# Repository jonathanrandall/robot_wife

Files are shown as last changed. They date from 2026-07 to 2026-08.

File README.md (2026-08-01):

# Robot Wife — Jessica

<p align="center">
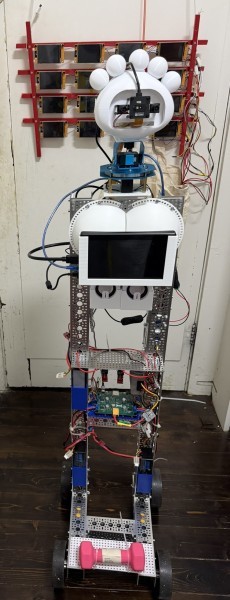
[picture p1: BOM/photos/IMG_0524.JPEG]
  
  &nbsp;&nbsp;
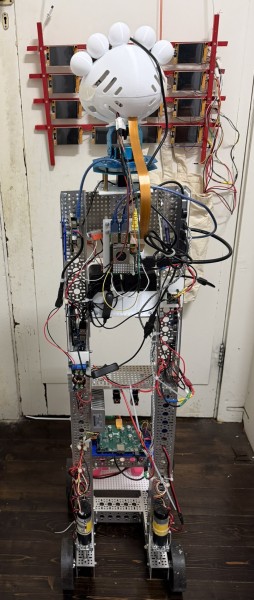
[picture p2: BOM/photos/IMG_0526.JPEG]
  
</p>

A personal robotics project: a conversational, physically expressive companion robot called **Jessica**. She drives around on four wheels, moves her head with a pan-tilt servo, lights up her LED hair, sees through a stereo USB camera, listens via microphone, and speaks through a USB speaker — all coordinated by a Raspberry Pi 5 running ROS 2 and an ESP32-S3 handling the low-level motor and servo control.

---

## Hardware Overview

| Component | Details |
|---|---|
| **Brain** | Raspberry Pi 5 |
| **Motor / Servo Controller** | Custom ESP32-S3 PCB (PlatformIO/Arduino firmware) |
| **Drive system** | 4-wheel differential drive, 4× motors with 1425 CPR quadrature encoders |
| **Motor drivers** | 4× VNH7040 H-bridge ICs controlled via MCP23017 I2C GPIO expander — [GitHub repo](https://github.com/jonathanrandall/four_motor_controller) containing KiCad schematic, PCB layout and bill of materials / [build video](https://youtu.be/qtjofj0y1YY) |
| **Head** | [Poppy Eva Head](https://github.com/poppy-project/Poppy-eva-head-design) — pan-tilt mount with 2× bus servos (xArm-compatible) |
| **Head servo controller** | ESP32 running MicroPython — bridges UART commands from the Pi to the servo bus |
| **Hair LEDs** | 5× WS2811 addressable LEDs via Raspberry Pi SPI (GPIO 10 / MOSI) |
| **Face display** | Waveshare 7" touchscreen — animated UI (listening / thinking / talking / idle) |
| **Stereo camera** | USB 3D stereo camera — published as compressed JPEG at 30 Hz |
| **ToF depth camera** | Arducam ToF (CSI) — published as lossless PNG depth map at 10 Hz |
| **Speaker** | USB audio device — text-to-speech via Piper TTS (on laptop) |
| **Microphone** | USB audio device — speech recognition via Whisper (on laptop) |
| **PC** | Any Linux machine with a GPU — runs MediaPipe pose/hand estimation, Whisper STT, Piper TTS, and Ollama |
| **Power** | LiPo battery with buck converter; 3D-printed battery holder |

---

## Repository Structure

```
robot_wife/
├── esp32_bridge/                # ESP32-S3 PlatformIO firmware (motors + drive servos)
│   ├── src/
│   │   ├── main.cpp                   — entry point, configuration, FreeRTOS tasks
│   │   ├── Motor.cpp                  — VNH7040 H-bridge driver (PWM + encoder)
│   │   ├── Mcp23017Bus.cpp            — I2C GPIO expander driver
│   │   ├── QuadratureEncoder.cpp      — hardware PCNT quadrature decoder
│   │   ├── PIDController.cpp          — general-purpose PID
│   │   ├── RobotController.cpp        — differential drive kinematics + 4× PID
│   │   ├── PanTiltController.cpp      — servo pan-tilt head control
│   │   └── WebDashboard.cpp           — WiFi web UI + REST telemetry API
│   ├── include/                       — corresponding header files
│   └── DOCUMENTATION.md              — detailed ESP32 firmware reference
│
├── micropython_servo_control/   # MicroPython firmware for the head servo ESP32
│   ├── main.py                        — UART serial bridge → xArm bus servo protocol
│   ├── config.py                      — servo IDs, limits, unit↔radian mapping
│   ├── BusServo.py                    — half-duplex bus servo driver
│   └── Oled.py                        — optional OLED status display
│
├── from_pi/                     # ROS 2 packages that run on the Raspberry Pi
│   ├── launcher/
│   │   └── jessica_launcher.py        — touch-screen power-on menu (no ROS needed)
│   └── src/
│       ├── jessica_robot/             — main robot package
│       │   ├── jessica_robot/
│       │   │   ├── jessica_chatbot.py       — AI conversation loop (Ollama LLM)
│       │   │   ├── hair_led_node.py         — WS2811 LED strip ROS node
│       │   │   ├── pan_tilt_teleop.py       — joystick head control node
│       │   │   ├── person_follower.py       — base + head follow person (visual servo)
│       │   │   ├── finger_follower.py       — head tracks raised index finger
│       │   │   └── stop_gesture.py          — raised-palm stop detection
│       │   ├── config/                — controller YAML, joystick mapping, twist_mux
│       │   ├── tools/
│       │   │   └── build_examples.py        — build few-shot / fine-tune examples from logs
│       │   └── launch/
│       │       └── jessica.launch.py        — full system launch file
│       ├── jessica_description/       — URDF / xacro robot model
│       ├── jessica_display/           — Waveshare 7" touchscreen UI (pygame/KMS)
│       │   └── jessica_display/
│       │       └── display_node.py          — listening/thinking/talking/idle animations
│       ├── esp32_combined_hardware/   — ros2_control hardware interface (wheels + head servos)
│       │   └── src/
│       │       ├── esp32_combined_hardware.cpp — serial bridge to ESP32
│       │       └── joy_button_bridge.cpp       — joystick buttons → ROS topics
│       ├── esp32_servo_hardware/      — ros2_control hardware interface (head servos only)
│       ├── camera_publisher/          — USB stereo camera → /jessica/camera/image/compressed
│       └── tof_publisher/             — Arducam ToF → /jessica/tof/image/compressed
│
├── robot_pc_ws/                 # ROS 2 workspace that runs on the GPU laptop / PC
│   └── src/
│       └── stereo_pose_publisher/     — MediaPipe pose + hand estimation on stereo frames
│           └── stereo_pose_node.py          — publishes PersonState + HandState
│
├── text_to_speech/              # Laptop-side servers
│   ├── whisper_server.py              — faster-whisper STT server (CUDA, port 8765)
│   └── tts_server.py                  — Piper TTS server (port 8766)
│
└── 3d_prints/                   # FreeCAD macros and STL files for printed parts
    ├── macros/                        — FreeCAD parametric macros (.FCMacro)
    └── *.stl                          — ready-to-print STL files
```

---

## Software Architecture

```
                         Raspberry Pi 5
┌──────────────────────────────────────────────────────────────┐
│                                                              │
│  jessica_launcher.py  (systemd, no ROS)                      │
│    └─ touch-screen menu → spawns / stops ros2 launch         │
│                                                              │
│  jessica_chatbot.py                                          │
│    ├─ records microphone (sounddevice)                       │
│    ├─ transcribes via Whisper server (HTTP → PC)             │
│    ├─ sends conversation to Ollama (HTTP → PC)               │
│    ├─ synthesises speech reply via TTS server (HTTP → PC)    │
│    ├─ plays audio (aplay → USB speaker)                      │
│    ├─ logs every turn to ~/jessica_ws/logs/ (JSONL)          │
│    ├─ publishes /jessica/hair_hue    (Int32)                 │
│    ├─ publishes /jessica/ui_state    (String → display)      │
│    ├─ publishes /jessica/speech_env  (Float32MultiArray)     │
│    ├─ publishes /cmd_vel             (Twist, autonomous)     │
│    └─ publishes /pan_tilt_controller/joint_trajectory        │
│                                                              │
│  display_node.py                                             │
│    └─ /jessica/ui_state + /jessica/speech_env → Waveshare 7"│
│                                                              │
│  hair_led_node.py                                            │
│    └─ /jessica/hair_hue → WS2811 LEDs (SPI)                 │
│                                                              │
│  webcam_publisher.py   → /jessica/camera/image/compressed    │
│  tof_publisher.py      → /jessica/tof/image/compressed       │
│                                                              │
│  pan_tilt_teleop.py  (joystick head)                         │
│  person_follower.py  (follow person; toggled by chatbot)     │
│  finger_follower.py  (follow finger; toggled by chatbot)     │
│                                                              │
│  twist_mux  (joystick > chatbot > follower priority)         │
│    └─ → /diff_cont/cmd_vel                                   │
│                                                              │
│  esp32_combined_hardware  (ros2_control plugin)              │
│    ├─ diff_cont → USB serial → ESP32-S3 (motors + encoders) │
│    └─ pan_tilt_controller → UART → MicroPython ESP32 →      │
│                             bus servos (pan + tilt)          │
│                                                              │
└──────────────────────────────────────────────────────────────┘
         │ USB serial (115200)        │ UART (115200)
         ▼                            ▼
    ESP32-S3 Firmware          MicroPython ESP32
┌─────────────────────┐   ┌──────────────────────────┐
│ 4× PID motor loops  │   │ xArm bus servo protocol  │
│ Serial ROS bridge   │   │ pan servo (ID 6)         │
│ WiFi web dashboard  │   │ tilt servo (ID 5)        │
└─────────────────────┘   └──────────────────────────┘

                         GPU Laptop / PC
┌──────────────────────────────────────────────────────────────┐
│  whisper_server.py  (port 8765) — faster-whisper CUDA STT   │
│  tts_server.py      (port 8766) — Piper TTS synthesis       │
│  Ollama             (port 11434) — local LLM (llama3.2:3b)  │
│  stereo_pose_node.py — MediaPipe on stereo frames           │
│    ├─ publishes /jessica/person_state  (PersonState)         │
│    └─ publishes /jessica/hand_state    (HandState)           │
└──────────────────────────────────────────────────────────────┘
```

---

## ESP32-S3 Motor Firmware

The firmware lives in `esp32_bridge/` and is built with PlatformIO (Arduino framework). See [`esp32_bridge/DOCUMENTATION.md`](esp32_bridge/DOCUMENTATION.md) for the full software reference including pin assignments, PID tuning guide, serial protocol, and web API.

### Quick summary

- **4-wheel differential drive** with independent closed-loop PID speed control per wheel
- **Quadrature encoder** reading via ESP32-S3 hardware PCNT peripheral (64-bit position)
- **VNH7040** H-bridge motor drivers; direction and MultiSense current sensing via MCP23017
- **ROS 2 serial interface** at 115200 baud — accepts wheel speed commands, returns encoder velocities
- **Serial watchdog** — motors stop automatically if no command received for 1 second
- **WiFi web dashboard** at `http://robot.local` — telemetry, manual drive, PWM readout

### Build and flash

```bash
cd esp32_bridge
pio run --target upload
pio device monitor
```

### WiFi configuration

Edit the top of `esp32_bridge/src/main.cpp`:

```cpp
const char* WIFI_SSID     = "your-network";
const char* WIFI_PASSWORD = "your-password";
```

---

## MicroPython Head Servo Controller

The pan-tilt head uses xArm-compatible bus servos driven by a separate ESP32 running MicroPython. Code is in `micropython_servo_control/`.

`main.py` listens for newline-terminated text commands on two links simultaneously:

- **UART1** (pins 16/17) — the Pi link, used by `esp32_servo_hardware` (ros2_control)
- **USB serial** — for bench testing from a laptop

### Command protocol

| Command | Example | Description |
|---|---|---|
| `ptr <pan_rad> <tilt_rad> [ms]` | `ptr 0.5 -0.3 1000` | Move both axes in radians |
| `pr <rad> [ms]` | `pr 0.5` | Pan only (radians) |
| `tr <rad> [ms]` | `tr -0.3` | Tilt only (radians) |
| `pt <pan> <tilt> [ms]` | `pt 600 400` | Move both in servo units (0–1000) |
| `pos` | `pos` | Report current positions |

Every command gets a JSON reply shaped like `sensor_msgs/JointState`:

```json
{"name": ["pan_joint", "tilt_joint"], "position": [0.0, -0.3]}
```

Servo units: 500 = 0 rad, 0 = −135°, 1000 = +135°. Per-servo limits and direction signs are in `config.py`.

---

## ROS 2 Setup (Raspberry Pi)

The Pi runs **ROS 2 Jazzy**. All packages live in `from_pi/src/` and are built with colcon.

```bash
cd from_pi
colcon build
source install/setup.bash

# Full robot (hardware + cameras + chatbot + display)
ros2 launch jessica_robot jessica.launch.py

# Chatbot + LEDs only (no ESP32 / joystick)
ros2 launch jessica_robot jessica.launch.py hardware:=false
```

### Key ROS topics

| Topic | Type | Publisher → Subscriber |
|---|---|---|
| `/jessica/hair_hue` | `std_msgs/Int32` | chatbot → hair_led_node |
| `/jessica/ui_state` | `std_msgs/String` | chatbot → display_node |
| `/jessica/speech_env` | `std_msgs/Float32MultiArray` | chatbot → display_node |
| `/jessica/touch` | `geometry_msgs/Point` | display_node → chatbot |
| `/jessica/camera/image/compressed` | `sensor_msgs/CompressedImage` | camera_publisher → PC |
| `/jessica/tof/image/compressed` | `sensor_msgs/CompressedImage` | tof_publisher → PC |
| `/jessica/person_state` | `PersonState` | PC stereo_pose_node → person_follower |
| `/jessica/hand_state` | `HandState` | PC stereo_pose_node → finger_follower |
| `/jessica/person_follow/enable` | `std_msgs/Bool` | chatbot → person_follower |
| `/jessica/finger_follow/enable` | `std_msgs/Bool` | chatbot → finger_follower |
| `/cmd_vel` | `geometry_msgs/Twist` | chatbot (autonomous) → twist_mux |
| `/cmd_vel_joy` | `geometry_msgs/Twist` | joystick teleop → twist_mux |
| `/diff_cont/cmd_vel` | `geometry_msgs/Twist` | twist_mux → diff drive controller |
| `/pan_tilt_controller/joint_trajectory` | `trajectory_msgs/JointTrajectory` | chatbot / teleop → head controller |
| `/joy` | `sensor_msgs/Joy` | joy_node → teleop nodes |

---

## AI Chatbot — Jessica

`jessica_chatbot.py` implements the full conversation loop:

1. **Listen** — records microphone until a pause is detected
2. **Transcribe** — sends WAV to the laptop Whisper server (`POST /transcribe`)
3. **Think** — sends conversation history to Ollama (`llama3.2:3b` by default)
4. **Execute** — parses JSON response for a robot command (`drive`, `turn`, `look`, `wave`, `nod`, `shake_head`, `change_hair_color`, `stop`, or `none`)
5. **Speak** — requests synthesised audio from the TTS server, plays through USB speaker
6. **Log** — appends a turn record to `~/jessica_ws/logs/jessica_YYYY-MM-DD.jsonl`

Jessica only acts on robot commands when the user begins with **"Jessica darling"**.

### Conversation states

| State | Behaviour |
|---|---|
| `IDLE` | Listens indefinitely; any speech starts a conversation |
| `CONVERSATION` | Active conversation; 30 s silence returns to IDLE |
| `DORMANT` | Silent after "bye Jessica"; wakes on "Jessica darling" / "hello Jessica" |

### Spoken feedback logging

Say a feedback phrase immediately after Jessica acts to label the turn for later training:

- **Approval** — "good girl", "well done", "that was perfect" → logs `label: good`
- **Correction** — "that was wrong", "wrong Jessica" → logs `label: bad` with your spoken words

`from_pi/src/jessica_robot/tools/build_examples.py` processes the logs into few-shot examples or fine-tuning pairs:

```bash
python3 src/jessica_robot/tools/build_examples.py --prompt   # print confirmed examples
python3 src/jessica_robot/tools/build_examples.py --label bad # review corrections
```

---

## Face Display

`display_node.py` drives the Waveshare 7" touchscreen using **pygame over KMS/DRM** (no desktop required). It subscribes to `/jessica/ui_state` and `/jessica/speech_env` and renders:

| State | Visual |
|---|---|
| `listening` | "Listening..." text, ping-pong pink→yellow hue cycle |
| `thinking` | "Thinking..." text, ping-pong green→blue hue cycle |
| `talking` | Animated soundwaves, amplitude driven by speech envelope |
| `idle` | Dim breathing dot, low frame rate |

Touch events are published on `/jessica/touch`.

The `jessica_launcher.py` script provides a three-button power-on menu (Start Jessica / Chatbot Only / Drive Mode) that runs before ROS and releases the display to `jessica_display` when a stack is started. Hold the screen for 3 seconds to stop the stack and return to the menu.

---

## Vision — Person and Finger Following

Two visual-servo nodes run on the Pi and are voice-toggled by the chatbot (say **"Jessica darling, follow me"** / **"Jessica darling, stop following"**):

- **`person_follower.py`** — head and base follow the person's shoulder midpoint. Auto-stops if the person turns to face the robot or raises an open palm.
- **`finger_follower.py`** — head tracks a raised index finger; only the head moves.

Both rely on `PersonState` and `HandState` messages published by `stereo_pose_node.py` running on the PC (MediaPipe PoseLandmarker + HandLandmarker on rectified stereo frames).

---

## Laptop / PC Services

All GPU-intensive work is offloaded to a laptop or desktop on the same LAN.

### Whisper STT server (port 8765)

```bash
cd text_to_speech
pip install fastapi uvicorn faster-whisper
python whisper_server.py
```

Override model or port: `WHISPER_MODEL=medium.en WHISPER_PORT=8765 python whisper_server.py`

### Piper TTS server (port 8766)

```bash
cd text_to_speech
pip install fastapi uvicorn piper-tts numpy
python tts_server.py
```

The voice model is bundled in `text_to_speech/voices/`. Override: `TTS_VOICE_MODEL=/path/to/model.onnx python tts_server.py`

### MediaPipe pose estimator (robot_pc_ws)

```bash
cd robot_pc_ws
colcon build
source install/setup.bash
ros2 launch stereo_pose_publisher stereo_pose.launch.py
```

Update `WHISPER_URL`, `OLLAMA_URL`, and `TTS_URL` at the top of `jessica_chatbot.py` to match your PC's IP address.

---

## Hair LED Node

`hair_led_node.py` controls a strip of **5× WS2811** LEDs via Raspberry Pi SPI. Subscribes to `/jessica/hair_hue` (Int32):

| Value | Colour |
|---|---|
| 0–359 | HSV hue in degrees (S=100%, V=80%) |
| -1 | White |
| -2 | Rainbow (each LED a different colour) |

**Wiring:** data → GPIO 10 (SPI0 MOSI, physical pin 19). Enable SPI in `/boot/firmware/config.txt`:

```
dtparam=spi=on
```

---

## 3D Printed Parts

All STL files and FreeCAD macros are in `3d_prints/`.

| File | Description |
|---|---|
| `battery_holder.stl` | LiPo battery mount |
| `buck_converter_mount.stl` | Voltage regulator bracket |
| `camera_stand_final_v6-Body.stl` | USB stereo camera stand |
| `led_boobs.stl` / `wife_boobs_v2_13.stl` | LED diffuser enclosures |
| `light_diffuser_Sphere.stl` | Hemisphere light diffuser |
| `mount_holders.stl` | General component mounts |
| `pi_holder.stl` | Raspberry Pi mount |
| `servo_head_connection-Body.stl` | Pan-tilt servo bracket |
| `Speaker_Box.stl` | USB speaker enclosure |
| `Switch_holderv2.stl` | Power switch holder |
| `macros/` | FreeCAD `.FCMacro` parametric source files |

---

## Security Notes

This project assumes a **trusted private LAN**. Nothing here should be exposed to the internet.

- **WiFi credentials** belong only in `esp32_bridge/src/main.cpp`, committed with an **empty password field**. Fill it in locally and do not commit the change.
- **The ESP32 web dashboard has no authentication.** Keep the robot on a private network.
- **The Whisper, TTS, and Ollama servers are unauthenticated** and bind to `0.0.0.0`. Run them only behind your router's firewall.
- No API keys, tokens, or private keys are used anywhere — all AI services run locally.

---

## License

The software and hardware designs in this repository are released under two licenses:

- **MIT License** — all software, firmware, and original hardware designs. See [LICENSE](LICENSE).

- **Creative Commons License** — the robot head is based on the **[Poppy Eva Head](https://github.com/poppy-project/Poppy-eva-head-design)** by the Poppy Project. The original design is released under the [Creative Commons Attribution-ShareAlike 4.0 International (CC BY-SA 4.0)](https://creativecommons.org/licenses/by-sa/4.0/) license. Any derivative head designs in this repository are shared under the same CC BY-SA 4.0 terms.

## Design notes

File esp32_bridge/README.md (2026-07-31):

# ESP32 Bridge — Motor & Drive Firmware

PlatformIO/Arduino firmware for the custom ESP32-S3 PCB that handles all motor control and drive servo functions.

Datasheets for the key ICs are included in this directory:
- `vnh7040_datasheet.pdf` — VNH7040 H-bridge motor driver
- `MCP23017-Data-Sheet-DS20001952.pdf` — MCP23017 I2C GPIO expander
- `AP63200-AP63201-AP63203-AP63205.pdf` — AP632xx buck converter

## Quick start

```bash
pio run --target upload
pio device monitor
```

## What it does

- Closed-loop PID speed control for 4 drive motors (VNH7040 H-bridges via MCP23017)
- Quadrature encoder reading via ESP32-S3 hardware PCNT (64-bit, 1425 CPR)
- ROS 2 compatible serial interface over USB-CDC at 115200 baud
- Serial watchdog — motors stop if no command received within 1 second
- WiFi web dashboard at `http://robot.local` for manual control and telemetry

## Configuration

All user-facing settings are at the top of `src/main.cpp`: WiFi credentials, wheel dimensions, encoder CPR, PID gains, and pin assignments.

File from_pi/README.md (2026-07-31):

# from_pi — Raspberry Pi ROS 2 Workspace

All ROS 2 packages that run on the Raspberry Pi 5. Built with colcon (ROS 2 Jazzy).

## Build

```bash
cd from_pi
colcon build
source install/setup.bash
```

## Launch

```bash
# Full robot — hardware + cameras + chatbot + display
ros2 launch jessica_robot jessica.launch.py

# Chatbot + LEDs only (no ESP32 / joystick)
ros2 launch jessica_robot jessica.launch.py hardware:=false
```

## Packages

| Package | Description |
|---|---|
| `jessica_robot` | Main package — chatbot, LEDs, head teleop, following nodes, launch file |
| `jessica_display` | Waveshare 7" touchscreen animated UI |
| `jessica_description` | URDF/xacro robot model |
| `esp32_combined_hardware` | ros2_control plugin — serial bridge to ESP32-S3 (4 wheels + head servos) |
| `esp32_servo_hardware` | ros2_control plugin — serial bridge to MicroPython head servo ESP32 |
| `camera_publisher` | USB stereo camera → `/jessica/camera/image/compressed` |
| `tof_publisher` | Arducam ToF depth camera → `/jessica/tof/image/compressed` |
| `person_state_msgs` | Custom message definitions (PersonState, HandState, Landmark) |

The `launcher/` directory contains `jessica_launcher.py` — a standalone (non-ROS) touch-screen power-on menu.

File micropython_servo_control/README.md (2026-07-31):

# MicroPython Servo Control

MicroPython firmware for the ESP32 that controls Jessica's pan-tilt head servos (xArm-compatible bus servos).

This board sits between the Raspberry Pi and the servo bus. The Pi sends text commands over UART; this firmware translates them to the half-duplex bus servo protocol.

## Files

| File | Description |
|---|---|
| `main.py` | Main loop — listens on UART + USB, parses commands, drives servos |
| `config.py` | Servo IDs, pin assignments, limits, unit↔radian mapping |
| `BusServo.py` | Half-duplex xArm bus servo driver |
| `Oled.py` | Optional SSD1306 OLED status display driver |
| `wifi_stuff.py` | Legacy WiFi web UI (unused — kept as reference) |
| `main_wifi_backup.py` / `main_espnow_backup.py` | Earlier prototype versions |

## Command protocol

Commands are newline-terminated text, accepted on UART1 (Pi link) and USB simultaneously. Every command gets a JSON reply:

```json
{"name": ["pan_joint", "tilt_joint"], "position": [0.0, -0.3]}
```

| Command | Example | Description |
|---|---|---|
| `ptr <pan_rad> <tilt_rad> [ms]` | `ptr 0.5 -0.3 1000` | Move both axes in radians |
| `pr <rad> [ms]` | `pr 0.5` | Pan only |
| `tr <rad> [ms]` | `tr -0.3` | Tilt only |
| `pt <pan> <tilt> [ms]` | `pt 600 400` | Move both in servo units (0–1000) |
| `pos` | `pos` | Report current positions |

Servo units: 500 = 0 rad, 0 = −135°, 1000 = +135°. Per-servo limits and direction signs are in `config.py`.

## Wiring (xArm ESP32 board)

| Signal | Pin |
|---|-----|
| Servo bus TX | GPIO 26 |
| Servo bus RX | GPIO 35 |
| Servo TX enable | GPIO 25 |
| Servo RX enable | GPIO 12 |
| UART1 TX (Pi link) | GPIO 17 |
| UART1 RX (Pi link) | GPIO 16 |
| OLED SCL | GPIO 27 |
| OLED SDA | GPIO 14 |

Pan servo = ID 6, Tilt servo = ID 5.

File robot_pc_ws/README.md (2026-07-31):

# robot_pc_ws — PC / Laptop ROS 2 Workspace

ROS 2 packages that run on the GPU-equipped laptop or desktop PC. Built with colcon (ROS 2 Jazzy).

## Build

```bash
cd robot_pc_ws
colcon build
source install/setup.bash
```

## Packages

| Package | Description |
|---|---|
| `stereo_pose_publisher` | MediaPipe pose + hand estimation on stereo camera frames |
| `jessica_description` | Copy of the robot URDF model (for RViz on the PC) |
| `person_state_msgs` | Custom message definitions shared with the Pi |

## Why on the PC?

MediaPipe pose and hand estimation is too CPU-intensive for the Raspberry Pi 5 at useful frame rates. Running it on the PC with a GPU keeps latency low and leaves the Pi free for the control stack.

The PC communicates with the Pi over the LAN via standard ROS 2 DDS (same `ROS_DOMAIN_ID`).

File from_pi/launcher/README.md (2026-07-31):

# Jessica Launcher

A standalone power-on menu for the Waveshare 7" touchscreen. Runs outside ROS (no `ros2` dependency at runtime) so it can start from systemd before anything else.

## What it does

Presents three touch buttons:

| Button | Action |
|---|---|
| **Start Jessica** | Full robot — hardware + cameras + chatbot + display |
| **Chatbot Only** | Mic/speakers/display, no ESP32s or joystick |
| **Drive Mode** | Hardware + cameras, no chatbot (gamepad control) |

While a stack is running, the launcher releases the display (KMS/DRM master) so `jessica_display` can use it. Hold the screen for ~3 seconds to stop the running stack and return to the menu.

Small corner buttons provide **Exit** (quit the launcher) and **Shutdown** (power off the Pi safely via `systemctl poweroff`).

## Logs

- `~/jessica_ws/logs/launcher.log` — launcher output
- `~/jessica_ws/logs/launcher_stack.log` — ros2 launch output (new file each start)

## Sudoers rule (one-time setup for shutdown button)

```bash
echo 'jonny ALL=(root) NOPASSWD: /usr/sbin/shutdown' | \
    sudo tee /etc/sudoers.d/010-jessica-shutdown >/dev/null
sudo chmod 440 /etc/sudoers.d/010-jessica-shutdown
```

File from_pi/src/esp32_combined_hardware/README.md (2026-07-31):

# esp32_combined_hardware

A `ros2_control` hardware interface plugin that bridges the ROS 2 controller manager to the ESP32-S3 motor firmware over USB serial.

Handles **6 joints**: 4 drive wheels (velocity interface) + 2 head servos (position interface, pan and tilt).

## How it works

- Opens the serial port (configured in the URDF `<hardware>` block, typically `/dev/esp32_motor`)
- Each control loop cycle: sends `m_v0_v1_v2_v3_\r` wheel speed commands and reads back encoder velocities
- Head servo positions are sent as `ptr <pan_rad> <tilt_rad>\r` to the MicroPython servo ESP32
- Baud rate: 115200; timeout must be less than the control loop period (25 ms at 30 Hz)

## Configuration (in jessica.urdf.xacro)

```xml
<param name="device">/dev/esp32_motor</param>
<param name="baud_rate">115200</param>
<param name="timeout_ms">25</param>
<param name="wheel_radius">7.2</param>       <!-- cm -->
<param name="enc_counts_per_rev">1425</param>
```

Also contains `joy_button_bridge` — maps joystick buttons to ROS topics (enable/disable following modes, etc.). Configured via `config/joy_button_mappings.yaml`.

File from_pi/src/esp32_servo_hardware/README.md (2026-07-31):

# esp32_servo_hardware

A `ros2_control` hardware interface plugin for the **head servos only** — an alternative to the combined interface in `esp32_combined_hardware`.

Communicates with the MicroPython ESP32 over a dedicated serial port using the same `ptr <pan_rad> <tilt_rad>` text protocol as the combined interface.

Use this plugin when the head servo ESP32 is on a separate serial port from the motor ESP32 (e.g. during development or when the motor board is not present).

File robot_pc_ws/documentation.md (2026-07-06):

# Jessica Robot — Stereo Vision and Pose System

## Overview

This workspace runs on the robot PC and processes the stereo camera stream
published by the Raspberry Pi.  It rectifies the fisheye images, runs MediaPipe
pose and hand estimation on both eyes, computes metric 3-D positions for each
landmark using stereo disparity, and publishes an annotated video stream (for
monitoring in rqt), a `PersonState` message, and a `HandState` message that
the RPi controller subscribes to for task execution.

```
RPi                              Robot PC
────────────────                 ──────────────────────────────────────
camera_publisher   ──────────►  stereo_pose_node
  /jessica/camera/               │  rectify (fisheye remap)
    image/compressed             │  MediaPipe PoseLandmarker (L + R eye)
                                 │  MediaPipe HandLandmarker (L + R eye)
                                 │  stereo depth (Q matrix)
                                 │  FPS overlay + skeleton annotation
                                 ▼
                    /jessica/camera/pose/compressed  → rqt image view
                    /jessica/person_state            → RPi controller
                    /jessica/hand_state              → RPi controller
```

---

## Packages

### `person_state_msgs`

Custom ROS 2 message definitions.  This is a CMake package so the generated
Python/C++ bindings are available to any node on the network.

---

#### `msg/Landmark.msg`

A single pose or hand landmark with 3-D position and validity flag.

| Field | Type | Description |
|---|---|---|
| `position` | `geometry_msgs/Point` | 3-D position in the camera optical frame (metres). Zero when `depth_valid` is false. |
| `visibility` | `float32` | MediaPipe visibility score [0, 1]. For pose: minimum of left-eye and right-eye scores. For hand: set to 1.0 (hand model does not output visibility). |
| `depth_valid` | `bool` | True when stereo depth was available and `position.z` is metric depth. |

---

#### `msg/PersonState.msg`

Full body pose state published at the camera frame rate.

| Field | Type | Description |
|---|---|---|
| `header` | `std_msgs/Header` | Timestamp and `frame_id` from the source image. Use with TF to transform positions into other frames. |
| `person_visible` | `bool` | True when at least one person was detected in this frame. All other fields are zero/false when this is false. |
| `nose` | `Landmark` | Nose tip. |
| `left_shoulder` | `Landmark` | Person's anatomical left shoulder. |
| `right_shoulder` | `Landmark` | Person's anatomical right shoulder. |
| `left_elbow` | `Landmark` | |
| `right_elbow` | `Landmark` | |
| `left_wrist` | `Landmark` | |
| `right_wrist` | `Landmark` | |
| `left_hip` | `Landmark` | |
| `right_hip` | `Landmark` | |
| `left_knee` | `Landmark` | |
| `right_knee` | `Landmark` | |
| `left_ankle` | `Landmark` | |
| `right_ankle` | `Landmark` | |
| `shoulder_midpoint` | `geometry_msgs/Point` | Midpoint of both shoulders in camera frame (metres). Primary reference for the following task. |
| `shoulder_midpoint_valid` | `bool` | True when both shoulders had valid stereo depth. |
| `pointing_active` | `bool` | True when a pointing gesture is detected. |
| `pointing_arm` | `uint8` | 0 = not pointing, 1 = left arm, 2 = right arm. |
| `pointing_ray` | `geometry_msgs/Vector3` | Unit direction vector (elbow → wrist) in the camera optical frame. Transform via TF to get the ray in the robot/world frame. |

> **Note:** MediaPipe labels left/right relative to the *person* (anatomical),
> not the camera.  `left_shoulder` is the person's anatomical left.

---

#### `msg/HandState.msg`

Hand landmark state for both hands, published at the camera frame rate.

| Field | Type | Description |
|---|---|---|
| `header` | `std_msgs/Header` | Timestamp and `frame_id` from the source image. |
| `left_hand_detected` | `bool` | True when a "Left" hand was detected in both eyes. |
| `right_hand_detected` | `bool` | True when a "Right" hand was detected in both eyes. |
| `left_hand_landmarks` | `Landmark[21]` | All 21 landmarks for the left hand (camera optical frame, metres). |
| `right_hand_landmarks` | `Landmark[21]` | All 21 landmarks for the right hand. |
| `left_index_tip` | `Landmark` | Convenience field — index fingertip (landmark 8) of the left hand. |
| `right_index_tip` | `Landmark` | Convenience field — index fingertip (landmark 8) of the right hand. |

**Hand landmark indices**

```
0   wrist
1-4   thumb  (cmc, mcp, ip, tip)
5-8   index  (mcp, pip, dip, tip)  ← tip = 8
9-12  middle (mcp, pip, dip, tip)
13-16 ring   (mcp, pip, dip, tip)
17-20 pinky  (mcp, pip, dip, tip)
```

> **Handedness convention:** MediaPipe reports handedness from the camera's
> point of view (mirror convention).  For a person facing the camera,
> MediaPipe's "Left" hand is typically the person's anatomical *right* hand
> and vice versa.  Account for this in the controller.

---

### `stereo_pose_publisher`

#### `stereo_pose_node`

**Source:** `src/stereo_pose_publisher/stereo_pose_publisher/stereo_pose_node.py`

Subscribes to the side-by-side compressed image published by the Jessica stereo
camera (left eye | right eye, 640×240 px total). For every incoming frame it:

1. Splits the frame into a 320×240 left half and a 320×240 right half.
2. Applies fisheye lens rectification to each half using pre-computed remap
   tables from the calibration file.
3. Runs MediaPipe **PoseLandmarker** on each rectified half independently,
   detecting 33 body landmarks.
4. Runs MediaPipe **HandLandmarker** on each rectified half independently,
   detecting up to 2 hands with 21 landmarks each.
5. Draws the pose skeleton (green joints, red bones) and hand skeleton
   (cyan joints, magenta bones) on each half.
6. Annotates metric depth (Z) for the nose and both shoulders on the left eye
   image.
7. Draws a live FPS counter in the top-left corner of the combined image.
8. Re-combines the annotated halves side-by-side and publishes the result.
9. Builds and publishes `PersonState` (body landmarks, shoulder midpoint,
   pointing gesture) and `HandState` (hand landmarks, index fingertips).

**Parameters**

| Parameter | Type | Default | Description |
|---|---|---|---|
| `use_gpu_pose` | `bool` | `false` | Run the pose landmarker on the GPU. |
| `use_gpu_hand` | `bool` | `false` | Run the hand landmarker on the GPU. |

> **GPU note:** Both models default to CPU.  Running both on GPU simultaneously
> causes a MediaPipe tensor write-contention error (`Multiple writes to a Tensor
> instance`), and in practice both-CPU is also faster than the mixed CPU/GPU
> split.  GPU options are available for experimentation.

**Performance**

The four model inferences (pose-left, pose-right, hand-left, hand-right) run in
parallel via a `ThreadPoolExecutor` with 4 workers.  This means the per-frame
cost is roughly the time of the slowest single inference rather than the sum of
all four.  JPEG quality is set to 65 (reduced from 80) for faster encode/decode
with negligible visual difference at rqt viewing distances.

**Depth calculation**

After rectification, matching 3-D points lie on the same horizontal scan-line
in both eye images. For a landmark at pixel `x_L` (left) and `x_R` (right):

```
disparity  d = x_L - x_R                          (pixels, positive for real objects)
depth      Z = Q[2,3] / (Q[3,2] * d + Q[3,3])    (metres)
```

**Back-projection to camera frame**

Given metric depth `Z` and the rectified projection matrix `P1`:

```
X_cam = (x_px - cx) * Z / f
Y_cam = (y_px - cy) * Z / f
Z_cam = Z
```

The result is in the camera optical frame (Z forward, X right, Y down).

**Calibration values** (from `fisheye_stereo_charuco_calibration_v2.npz`)

| Parameter | Value |
|---|---|
| Focal length `f` | 185.05 px (rectified) |
| Principal point `cx` | 170.0 px |
| Principal point `cy` | 132.6 px |
| Stereo baseline | ~62 mm |
| Left RMS reprojection error | 0.336 px |
| Right RMS reprojection error | 0.346 px |
| Stereo RMS reprojection error | 0.440 px |

**Pointing detection**

An arm is classified as pointing when the elbow angle (shoulder–elbow–wrist)
exceeds 150°. The test uses 3-D metric positions so it is invariant to the
person's distance from the camera. The `pointing_ray` unit vector (elbow →
wrist direction in camera frame) is included in `PersonState` so the
controller can transform it via TF into the robot's reference frame.

**Configuration files** (in the package share directory)

| File | Description |
|---|---|
| `config/fisheye_stereo_charuco_calibration_v2.npz` | Fisheye stereo calibration — remap tables, Q matrix, P1 matrix |
| `config/pose_landmarker_full.task` | MediaPipe pose model. Swap for `pose_landmarker_lite.task` if CPU-bound. |
| `config/hand_landmarker.task` | MediaPipe hand model (21 landmarks per hand, up to 2 hands). |

---

## ROS Topics

| Topic | Type | Direction | Description |
|---|---|---|---|
| `/jessica/camera/image/compressed` | `sensor_msgs/CompressedImage` | Subscribe | Raw side-by-side stereo frame from RPi |
| `/jessica/camera/pose/compressed` | `sensor_msgs/CompressedImage` | Publish | Annotated frame with skeleton, depth labels, and FPS counter |
| `/jessica/person_state` | `person_state_msgs/PersonState` | Publish | 3-D body landmark positions, shoulder midpoint, pointing state |
| `/jessica/hand_state` | `person_state_msgs/HandState` | Publish | 3-D hand landmark positions, index fingertips |

---

## Running the System

### Prerequisites

- Camera publisher running on the RPi and reachable on the same ROS 2 network
- ROS 2 Jazzy installed on the robot PC
- Python venv at `~/venvs/jazzy` with `mediapipe` installed
- `empy==3.3.4` in the venv (see Notes below)

### Build

```bash
cd ~/projects/robot_wife/software/robot_pc_ws
source /opt/ros/jazzy/setup.bash

# Build the message package first (CMake — generates Python bindings)
colcon build --packages-select person_state_msgs

# Build the pose publisher (symlink-install so edits take effect immediately)
colcon build --packages-select stereo_pose_publisher --symlink-install
```

### Launch

```bash
source /opt/ros/jazzy/setup.bash
source install/setup.bash

# Default (both on CPU — fastest and avoids tensor contention error)
ros2 launch stereo_pose_publisher stereo_pose.launch.py

# Both on GPU (may trigger tensor contention error)
ros2 launch stereo_pose_publisher stereo_pose.launch.py use_gpu_pose:=true use_gpu_hand:=true
```

### View the annotated image in rqt

In a second terminal with the same environment sourced:

```bash
rqt
```

Inside rqt: **Plugins → Visualization → Image View**, then set the topic
drop-down to `/jessica/camera/pose/compressed`.

The FPS counter is displayed in the top-left corner of the image in green.

### Inspect topics

```bash
ros2 topic echo /jessica/person_state
ros2 topic echo /jessica/hand_state
ros2 topic hz   /jessica/camera/pose/compressed
```

---

## RViz — Live Robot Visualisation

RViz launches automatically alongside the pose nodes.  It renders the live robot
model using data published by the Raspberry Pi — no local `robot_state_publisher`
or `joint_state_publisher` is needed on this PC.

### How it works

| Data | Source |
|---|---|
| `/robot_description` | Pi's `robot_state_publisher` (transient-local, published once at startup) |
| `/tf` + `/tf_static` | Pi's `robot_state_publisher`, updated from real joint states |
| STL mesh files | Local filesystem — resolved from `jessica_description` built in this workspace |

The `jessica_description` package exists in this workspace **only** to make the
mesh files available at `package://jessica_description/...` paths.  Everything
else comes over the network.

### Build jessica_description

```bash
cd ~/projects/robot_wife/software/robot_pc_ws
source /opt/ros/jazzy/setup.bash
colcon build --packages-select jessica_description
source install/setup.bash
```

After this, `colcon build --packages-select stereo_pose_publisher` picks up the
`jessica_description` share path used in the launch file.

### Networking check (do this before the first launch)

```bash
ros2 topic echo /robot_description --once   # model XML from the Pi
ros2 topic echo /joint_states --once        # live joint values from the Pi
ros2 run tf2_tools view_frames              # (optional) confirm TF tree arrives
```

If these hang, the Pi and PC are not on the same `ROS_DOMAIN_ID` or not
discoverable over the LAN — fix that before launching.

### Fixed frame

`display.rviz` uses `base_link` as the fixed frame — suitable for watching the
head pan/tilt and wheels move.  To see the robot navigate around a world frame,
change the fixed frame to `odom` in the RViz Displays panel.

### Standalone model check (no robot connected)

The package ships its own `display.launch.py` with sliders for eyeballing mesh
positions offline:

```bash
ros2 launch jessica_description display.launch.py
```

**Do not run this at the same time as the live robot** — it starts its own
`robot_state_publisher` which would fight the Pi's.

### QoS note

The `display.rviz` in this workspace has `Durability Policy: Transient Local`
on the RobotModel's Description Topic.  This ensures RViz receives the
`/robot_description` message even when it starts after the Pi has already
published it.

---

## Planned Tasks

### Task 1 — Point and navigate

The person extends one arm to point in a direction and says "go over there"
(optionally with a distance command).

**Data flow:**
1. `stereo_pose_node` detects the pointing gesture and publishes `pointing_ray`
   in the camera optical frame inside `PersonState`.
2. The RPi controller applies a TF transform to convert the ray from the camera
   frame into the robot base frame (requires the camera → robot TF from the URDF).
3. The robot either rotates its head to look along the ray, or navigates in
   that direction (distance from the voice command).

### Task 2 — Follow me

The robot follows the person, maintaining a configurable relative position
(behind, left, or right — set by voice command).

**Data flow:**
1. `stereo_pose_node` publishes `shoulder_midpoint` (Z = distance, X = lateral
   offset in camera frame) inside `PersonState`.
2. The RPi controller drives the robot to maintain a target distance and lateral
   offset.
3. If following left or right: the head pan servo keeps the person centred.
4. If the person is lost (`person_visible == false`): the robot stops and pans
   the head to search until re-detection.

### Task 3 — Follow my finger (head tracking)

The person holds up their index finger and says "follow my finger".  The robot
head tracks the fingertip as it moves.

**Data flow:**
1. `stereo_pose_node` publishes `left_index_tip` or `right_index_tip` in
   `HandState` with 3-D position in camera frame.
2. The RPi controller computes pan/tilt error from the fingertip X, Y pixel
   position relative to the image centre.
3. A proportional (or PID) controller drives the pan-tilt servos to zero the
   error, keeping the fingertip centred in the image.
4. The LLM activates/deactivates this mode in response to voice commands —
   it does not participate in the real-time control loop.

---

## TF / URDF (TODO)

The camera is mounted on a pan-tilt servo. Once the URDF is written:

- The TF tree will include the camera optical frame so that `header.frame_id`
  in `PersonState` and `HandState` can be used directly with
  `tf2_ros.Buffer.transform()`.
- `pointing_ray`, landmark positions, and fingertip positions can be
  transformed into the robot base frame or world frame for navigation and
  head control.

---

## System Architecture Notes

**Processing split**

| Component | Runs on | Reason |
|---|---|---|
| Camera capture + publish | RPi | Low latency, close to hardware |
| Fisheye rectification | PC | Calibration data lives here |
| MediaPipe pose + hand | PC (CPU) | Too heavy for RPi; CPU faster than GPU for this setup |
| PersonState / HandState publish | PC | Output of PC processing |
| Servo PID control loops | RPi | Must be low latency, no network in loop |
| LLM (Llama 3.2:3b) | PC (GPU) | Shared GPU with Whisper + MediaPipe |
| Whisper STT | PC (GPU) | |

**GPU load (PC)**

Whisper small.en and Llama 3.2:3b share the GPU.  Both MediaPipe models
(pose and hand) default to CPU, which avoids a tensor write-contention error
that occurs when both run on the GPU simultaneously, and is also faster in
practice than the mixed CPU/GPU split.

**LLM role**

The LLM sets *modes* and *goals* (e.g. "start following", "stop", "go over
there") in response to voice commands.  The RPi executes those modes in tight
real-time loops.  The LLM is not in any control loop — only in the
command/intent layer.

---

## RPi Controller — Getting Started

This section is a quick-start guide for the Claude session running on the RPi
that will write the subscriber and finger-following code.

### Step 1 — Get the message package onto the Pi

The `person_state_msgs` package must be built on the Pi before any subscriber
can use it.  Copy the package from the PC:

```bash
# Run on the PC — adjust the Pi's hostname/IP as needed
scp -r ~/projects/robot_wife/software/robot_pc_ws/src/person_state_msgs \
    pi@jessica.local:~/ros2_ws/src/
```

Then on the Pi:

```bash
cd ~/ros2_ws
source /opt/ros/jazzy/setup.bash
colcon build --packages-select person_state_msgs
source install/setup.bash
```

### Step 2 — Topics to subscribe to

| Topic | Message type | Purpose |
|---|---|---|
| `/jessica/hand_state` | `person_state_msgs/HandState` | Index fingertip position for finger following |
| `/jessica/person_state` | `person_state_msgs/PersonState` | Body pose, shoulder midpoint, pointing |

### Step 3 — Key fields for finger following

Check detection first, then read the fingertip position:

```python
from person_state_msgs.msg import HandState

def hand_callback(msg: HandState):
    # Pick whichever hand is detected — prefer the one that is raised
    if msg.right_hand_detected and msg.right_index_tip.depth_valid:
        tip = msg.right_index_tip
    elif msg.left_hand_detected and msg.left_index_tip.depth_valid:
        tip = msg.left_index_tip
    else:
        return  # no hand visible

    # tip.position.x  — metres left/right in camera frame (right = positive)
    # tip.position.y  — metres up/down in camera frame   (down  = positive)
    # tip.position.z  — metric depth from camera (metres)
```

### Step 4 — Converting fingertip position to pan/tilt error

The camera image is 320×240 per eye.  The calibration values are:

| Value | Symbol | Number |
|---|---|---|
| Focal length | f | 185.05 px |
| Principal point x | cx | 170.0 px |
| Principal point y | cy | 132.6 px |
| Image centre x | — | 160 px  (EYE_WIDTH / 2) |
| Image centre y | — | 120 px  (EYE_HEIGHT / 2) |

Back-calculate pixel position from the 3-D point:

```python
f, cx, cy = 185.05, 170.0, 132.6

x_px = (tip.position.x / tip.position.z) * f + cx
y_px = (tip.position.y / tip.position.z) * f + cy

# Error from image centre (pixels)
pan_error  = x_px - 160   # positive = fingertip is to the right
tilt_error = y_px - 120   # positive = fingertip is below centre
```

Drive the pan servo to zero `pan_error` and the tilt servo to zero
`tilt_error`.  A simple proportional controller is a good starting point:

```python
PAN_GAIN  = 0.001   # tune these
TILT_GAIN = 0.001

pan_command  = -PAN_GAIN  * pan_error
tilt_command = -TILT_GAIN * tilt_error
```

### Step 5 — Handedness note

MediaPipe uses a **mirror convention** for hand labels.  For a person facing
the camera, MediaPipe's `right_hand` in `HandState` is typically the person's
anatomical *left* hand.  This does not affect finger following (you just use
whichever hand is raised) but matters for gesture interpretation.

### Step 6 — LLM mode activation

The finger-following loop should be a mode that the LLM activates and
deactivates in response to voice commands (e.g. "follow my finger" / "stop").
The LLM sets a flag; the RPi control loop reads that flag each cycle.  The LLM
should **not** be called inside the servo control loop — only at the
command/intent layer.

### Step 7 — Subscribing to PersonState (follow-me and point-and-navigate)

`PersonState` carries the full body skeleton, shoulder midpoint (for follow-me),
and the pointing ray (for point-and-navigate).

```python
from person_state_msgs.msg import PersonState

def person_callback(msg: PersonState):
    if not msg.person_visible:
        # Person lost — stop and search
        return

    # ── Follow-me ──────────────────────────────────────────────────────────
    # shoulder_midpoint is the average of both shoulders in camera frame (metres)
    # Z = distance to person,  X = lateral offset (positive = person to the right)
    if msg.shoulder_midpoint_valid:
        distance      = msg.shoulder_midpoint.z   # metres
        lateral_error = msg.shoulder_midpoint.x   # metres (positive = right)
        # Drive robot to maintain target distance; use lateral_error for steering

    # ── Point-and-navigate ──────────────────────────────────────────────────
    # pointing_arm:  0 = not pointing,  1 = person's left arm,  2 = person's right arm
    if msg.pointing_active:
        arm = msg.pointing_arm   # 1 or 2
        # pointing_ray is a unit vector in the camera optical frame
        # (Z forward, X right, Y down)
        ray_x = msg.pointing_ray.x
        ray_y = msg.pointing_ray.y
        ray_z = msg.pointing_ray.z
        # Transform this ray via TF into the robot base frame to get
        # the navigation direction.

    # ── Individual landmarks ────────────────────────────────────────────────
    # Each Landmark has:  .position.x / .y / .z  (metres, camera frame)
    #                     .visibility             (0-1 confidence)
    #                     .depth_valid            (True = z is metric)
    if msg.nose.depth_valid:
        nose_z = msg.nose.position.z   # distance to face
```

**Key PersonState fields summary**

| Field | When to use |
|---|---|
| `person_visible` | Gate all other fields — skip if False |
| `shoulder_midpoint` + `shoulder_midpoint_valid` | Primary follow-me reference point |
| `pointing_active` + `pointing_arm` + `pointing_ray` | Point-and-navigate gesture |
| `nose`, `left_shoulder`, `right_shoulder`, `left_wrist`, `right_wrist`, `left_elbow`, `right_elbow` | Any task needing specific body part positions |
| `left_hip`, `right_hip`, `left_knee`, `right_knee`, `left_ankle`, `right_ankle` | Lower body landmarks when visible |
| `header.frame_id` | Use with `tf2_ros.Buffer.transform()` once URDF/TF is set up |

### Step 8 — LLM mode activation for body-level tasks

Same pattern as finger following.  The LLM sets a mode string or enum
(e.g. `"follow_me"`, `"point_navigate"`, `"idle"`) in response to voice
commands.  The RPi control loop reads the mode each cycle and selects which
fields from `PersonState` and `HandState` to act on.  Never call the LLM inside
a control loop.

---

## Notes

- **`empy` version:** Running `pip install mediapipe` upgrades `empy` to 4.x
  which breaks `colcon build` for CMake packages.  If the build fails with a
  `TransientParseError`, fix it with:
  ```bash
  ~/venvs/jazzy/bin/pip install "empy==3.3.4"
  ```
- **Handedness:** MediaPipe hand handedness uses a mirror convention — for a
  person facing the camera, "Left" in the message is typically the person's
  anatomical right hand.
- **Pose left/right:** MediaPipe pose landmark labels are anatomical (relative
  to the person), so `left_shoulder` is the person's own left shoulder.
- **Model swap:** Replace `pose_landmarker_full.task` with
  `pose_landmarker_lite.task` in `config/` for faster but less accurate pose
  detection.  No code changes required.

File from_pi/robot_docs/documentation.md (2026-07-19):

# Jessica Robot — Project Documentation

Jessica is an AI companion robot on a Raspberry Pi 5: voice conversation via a
local LLM (Ollama on the PC), speech recognition, TTS, and hardware control
through ROS 2 / ros2_control — 4 mecanum-style wheels + a pan-tilt head on two
ESP32s, a stereo USB camera, a front ToF depth camera, WS2811 hair LEDs, and a
gamepad for manual override.

Contents:
1. [Launching](#1-launching)
2. [Topics — full list + commanding by topic](#2-topics)
3. [Packages](#3-packages)
4. [Appendices](#4-appendices) (Python env, hardware, audio, logging/"dreaming",
   wake-word plan, troubleshooting)

---

## 1. Launching

### Build first

```bash
cd ~/jessica_ws && colcon build && source install/setup.bash
```

(ROS Jazzy is already sourced in every shell; only the workspace overlay needs
sourcing after a build.)

### Touchscreen launcher (no SSH needed)

`~/jessica_ws/launcher/jessica_launcher.py` (outside the ROS packages — it
only spawns/stops `ros2 launch`) shows three big buttons on the Waveshare:
**Start Jessica** (full robot), **Chatbot Only** (`hardware:=false
camera:=false tof:=false`), **Drive Mode** (`chatbot:=false`). While a stack
runs, **hold a finger anywhere for 3 s** to stop it and return to the menu.
Small corner buttons: **Exit** (quit the launcher) and **Shutdown Pi** (safe
power-off) — both go through a confirm screen with "Back to menu". Shutdown
tries `systemctl poweroff`, then `sudo -n shutdown`; passwordless shutdown
needs a one-time sudoers rule (see `launcher/jessica_launcher.py` header).
Stack output goes to `~/jessica_ws/logs/launcher_stack.log`. For start-on-boot,
install `launcher/jessica-launcher.service` (instructions inside the file).

### The full robot

```bash
ros2 launch jessica_robot jessica.launch.py
```

Brings up **everything**: robot_state_publisher, controller_manager with both
hardware interfaces (wheels ESP32 + servo-head ESP32), `diff_cont`,
`pan_tilt_controller`, `joint_broad`, head homing, joystick stack, twist_mux,
stereo camera publisher, ToF depth publisher, finger/person followers,
stop-gesture watcher, chatbot, and hair LEDs.

Launch arguments (all optional):

| Argument | Default | Effect |
|---|---|---|
| `hardware:=false` | `true` | Skip ESP32s / controllers / joystick / followers. Chatbot + LEDs + cameras only — use when the robot hardware isn't connected, otherwise the launch spams errors. |
| `camera:=false` | `true` | Skip the USB stereo camera publisher (separate USB device, gated independently of `hardware`). |
| `tof:=false` | `true` | Skip the front ToF depth camera publisher (CSI device, independent of the others). |
| `display:=false` | `true` | Skip the touchscreen UI (Waveshare 7" on HDMI). |
| `chatbot:=false` | `true` | Skip the voice chatbot — drive-only mode (gamepad + manual topic publishing; mic and speakers untouched). |
| `gamepad_mode:=xinput\|dinput` | `auto` | Force a gamepad profile instead of auto-detecting from the driver. |

Examples:

```bash
# Bench: no ESP32s connected, but cameras + chatbot still useful
ros2 launch jessica_robot jessica.launch.py hardware:=false

# Everything except the ToF camera
ros2 launch jessica_robot jessica.launch.py tof:=false
```

### Launching packages individually

Each sensor/utility package can run on its own (useful for testing one thing
without the whole stack):

```bash
# Stereo USB camera → /jessica/camera/image/compressed (~22 Hz JPEG)
ros2 launch camera_publisher camera_publisher.launch.py
#   or: ros2 run camera_publisher webcam_publisher

# ToF depth camera → /jessica/tof/image/compressed (10 Hz PNG grayscale)
ros2 launch tof_publisher tof_publisher.launch.py
#   or: ros2 run tof_publisher tof_publisher

# Touchscreen UI (listening text / talking waves / touch out)
ros2 launch jessica_display jessica_display.launch.py
#   or: ros2 run jessica_display display_node

# Chatbot + LEDs without the launch file
ros2 run jessica_robot jessica_chatbot     # terminal 1
ros2 run jessica_robot hair_led_node       # terminal 2

# Followers / gesture watcher standalone (need the hardware stack + PC vision)
ros2 run jessica_robot finger_follower                                  # tracks immediately
ros2 run jessica_robot finger_follower --ros-args -p start_enabled:=false  # wait for enable
ros2 run jessica_robot person_follower
ros2 run jessica_robot stop_gesture
```

The motion stack (controller_manager + controllers) is not practical to start
by hand — use `jessica.launch.py` (with `camera:=false tof:=false` if you only
want motion). Head direction sanity test (stack must be running):

```bash
bash ~/jessica_ws/temp/test_head_directions.sh
```

### On the PC (vision + display)

```bash
ros2 launch stereo_pose_publisher stereo_pose.launch.py   # hand/person state from the stereo feed
rqt                                                       # Image View for the camera topics
```

---

## 2. Topics

### Command topics — controlling Jessica by topic instead of voice

| Topic | Type | What it does |
|---|---|---|
| `/cmd_vel` | `geometry_msgs/Twist` | Drive the base (autonomous input to twist_mux, priority 10) |
| `/cmd_vel_joy` | `geometry_msgs/Twist` | Joystick's input to twist_mux (priority 100 — beats `/cmd_vel`) |
| `/pan_tilt_controller/joint_trajectory` | `trajectory_msgs/JointTrajectory` | Move the head (pan/tilt, radians) |
| `/jessica/hair_hue` | `std_msgs/Int32` | Hair LED colour (hue 0-359, -1 white, -2 rainbow) |
| `/jessica/finger_follow/enable` | `std_msgs/Bool` | Head-tracks-fingertip mode on/off |
| `/jessica/person_follow/enable` | `std_msgs/Bool` | Follow-me (base + head) mode on/off |
| `/jessica/stop` | `std_msgs/Empty` | General stop: halts base, cancels timed moves, disables both followers |
| `/esp32_aux_cmd` | `std_msgs/String` | Raw command to the motor ESP32: `estop` / `estopclear` |
| `/jessica/ui_state` | `std_msgs/String` | Touchscreen mode: `listening` / `talking` / `idle` |
| `/jessica/speech_env` | `std_msgs/Float32MultiArray` | TTS speech envelope for the talking waves: `[frame_s, level0, level1, …]`, levels 0-1 |

**Drive the base.** `diff_cont` has a 0.5 s command timeout (and twist_mux the
same), so a single `--once` publish only moves the robot for half a second —
stream with `-r` and Ctrl+C to stop:

```bash
# forward at 0.15 m/s until Ctrl+C
ros2 topic pub -r 10 /cmd_vel geometry_msgs/msg/Twist "{linear: {x: 0.15}}"

# turn on the spot, 0.8 rad/s left
ros2 topic pub -r 10 /cmd_vel geometry_msgs/msg/Twist "{angular: {z: 0.8}}"
```

**Move the head.** Positions are radians, `[pan, tilt]`. Conventions (REP 103):
**+pan = left, +tilt = down**. Pan range ±2.36 rad (±135°), tilt limited to
−1.3 … 0.87 rad. `time_from_start` sets the move duration:

```bash
# look 45° left over 1.5 s
ros2 topic pub --once /pan_tilt_controller/joint_trajectory \
  trajectory_msgs/msg/JointTrajectory \
  "{joint_names: ['pan_joint', 'tilt_joint'],
    points: [{positions: [0.785, 0.0], time_from_start: {sec: 1, nanosec: 500000000}}]}"

# back to centre
ros2 topic pub --once /pan_tilt_controller/joint_trajectory \
  trajectory_msgs/msg/JointTrajectory \
  "{joint_names: ['pan_joint', 'tilt_joint'],
    points: [{positions: [0.0, 0.0], time_from_start: {sec: 1}}]}"
```

**Hair colour** (see the hue table under hair_led_node):

```bash
ros2 topic pub --once /jessica/hair_hue std_msgs/msg/Int32 "{data: 240}"   # blue
ros2 topic pub --once /jessica/hair_hue std_msgs/msg/Int32 "{data: -2}"    # rainbow
```

**Touchscreen states** (normally driven by the chatbot; handy for testing):

```bash
ros2 topic pub --once /jessica/ui_state std_msgs/msg/String "{data: listening}"
ros2 topic pub --once /jessica/ui_state std_msgs/msg/String "{data: idle}"
```

**Follower modes on/off:**

```bash
ros2 topic pub --once /jessica/finger_follow/enable std_msgs/msg/Bool "{data: true}"
ros2 topic pub --once /jessica/person_follow/enable std_msgs/msg/Bool "{data: false}"
```

**Stop everything** (same effect as the both-arms-raised gesture):

```bash
ros2 topic pub --once /jessica/stop std_msgs/msg/Empty "{}"
```

**Motor e-stop** (firmware-level, wheels only):

```bash
ros2 topic pub --once /esp32_aux_cmd std_msgs/msg/String "{data: estop}"
ros2 topic pub --once /esp32_aux_cmd std_msgs/msg/String "{data: estopclear}"
```

> Gotcha: `ros2 topic pub --once` blocks forever if there is **no subscriber**
> (e.g. the stack isn't running). If a command "freezes", check the stack is up.

### Sensor / state topics — published by the robot

| Topic | Type | Source | Notes |
|---|---|---|---|
| `/jessica/camera/image/compressed` | `sensor_msgs/CompressedImage` | webcam_publisher | Stereo side-by-side, 640×240 JPEG, ~22 Hz — feeds the PC vision |
| `/jessica/tof/image/compressed` | `sensor_msgs/CompressedImage` | tof_publisher | 240×180 mono8 PNG, 10 Hz. Gray = (2000 − depth_mm)·255/2000: 255 = at the lens, 0 = ≥2 m or invalid |
| `/joint_states` | `sensor_msgs/JointState` | joint_broad | All 6 joints (4 wheels + pan/tilt), 30 Hz — **the** source of truth for head pose |
| `/diff_cont/odom` | `nav_msgs/Odometry` | diff_cont | Wheel odometry |
| `/joy` | `sensor_msgs/Joy` | joy_node | Raw gamepad |
| `/jessica/touch` | `geometry_msgs/Point` | jessica_display | Touchscreen taps, x/y in pixels (1024×600) — for future on-screen controls |

Quick checks: `ros2 topic hz /jessica/tof/image/compressed`,
`ros2 topic echo /joint_states --once`. On the PC, view the camera topics in
`rqt` → Plugins → Visualization → Image View.

### Topics published by the PC (vision)

| Topic | Type | Notes |
|---|---|---|
| `/jessica/hand_state` | `person_state_msgs/HandState` | Index fingertip + hand landmarks, 3-D camera optical frame (Z fwd, X right, Y down, m) |
| `/jessica/person_state` | `person_state_msgs/PersonState` | Shoulder midpoint + landmarks, pointing ray |
| `/jessica/camera/pose/compressed` | `sensor_msgs/CompressedImage` | Annotated vision stream (optional, for rqt) |

### Internal topics (don't publish to these by hand)

`/diff_cont/cmd_vel_unstamped` (twist_mux output) → `/diff_cont/cmd_vel`
(stamped, into the controller); `/robot_description`; `/dynamic_joint_states`.

---

## 3. Packages

```
jessica_ws/src/
├── jessica_robot/            # Nodes (chatbot, LEDs, followers), config, main launch
├── jessica_description/      # URDF/xacro + meshes + ros2_control config
├── esp32_combined_hardware/  # ros2_control hardware interface: 4 wheels (motor ESP32)
├── esp32_servo_hardware/     # ros2_control hardware interface: pan/tilt head (servo ESP32)
├── camera_publisher/         # USB stereo camera → compressed image topic
├── tof_publisher/            # Arducam ToF depth camera → grayscale depth topic
├── jessica_display/          # Waveshare 7" touchscreen UI (KMS/DRM, pygame)
└── person_state_msgs/        # HandState / PersonState message definitions (shared with PC)
```

### jessica_robot

Owns the top-level launch (`jessica.launch.py`), all config yaml
(controllers, twist_mux, gamepad profiles) and Jessica's Python nodes:

- **jessica_chatbot** — the brain. Voice loop (arecord → Whisper on the PC →
  Ollama → Piper TTS), robot-command parsing and execution, conversation
  logging. Detailed behaviour in [Appendix: Chatbot](#chatbot-behaviour).
- **hair_led_node** — WS2811 hair LEDs, subscribes `/jessica/hair_hue`
  (`pi5neo` via SPI; `rpi_ws281x` doesn't support the Pi 5). Hue values:

  | Value | Colour | | Value | Colour |
  |---|---|---|---|---|
  | 0 | red | | 240 | blue |
  | 25 | orange | | 270 | purple |
  | 60 | yellow | | 300 | magenta |
  | 120 | green | | 340 | pink |
  | 180 | cyan | | -1 / -2 | white / rainbow |

- **pan_tilt_teleop** — gamepad stick → head trajectories.
- **finger_follower** — head visual-servo on the raised index fingertip from
  `/jessica/hand_state`. Gated by `/jessica/finger_follow/enable`; comes up
  disabled in the launch. 20 Hz P-loop; tune with
  `ros2 param set /finger_follower pan_gain 0.0015` etc.
  (params: `pan_gain`/`tilt_gain` 0.0015, `pan_sign`/`tilt_sign` −1.0,
  `deadband_px` 8, `max_step_rad` 0.12, `control_rate` 20, `lost_timeout` 0.7).
- **person_follower** — "follow me": head servo on the shoulder midpoint from
  `/jessica/person_state` + base P-control holding 0.70 m distance
  (never reverses toward you, stops inside 0.5 m). Steering = current pan
  angle + in-image offset. Auto-stops when you turn to face the robot
  (shoulder x-order flips) or raise an open palm (only checked while
  following). Gated by `/jessica/person_follow/enable`, starts disabled.
  Joystick always overrides via twist_mux priority. Side-offset modes are
  planned but only `behind` is implemented.
- **stop_gesture** — always-on watcher: both wrists above the shoulders for
  ~0.4 s → one `std_msgs/Empty` on `/jessica/stop`. Every mover (chatbot,
  both followers) subscribes and stops itself — no single point of failure,
  and it runs on the spin thread so it works even while Jessica is
  recording/speaking (gesture-to-stopped well under 0.5 s). Tune:
  `ros2 param set /stop_gesture wrist_margin 0.08`, `hold_s`, `refire_s`.

### jessica_description

URDF/xacro (`description/jessica.urdf.xacro`) + gobilda meshes. The
`ros2_control.xacro` declares **two** hardware systems in one controller
manager: `JessicaESP32` (wheels, `/dev/esp32_motor`) and `JessicaServoHead`
(head, `/dev/esp32_servo`). Tilt command limits −1.3 … 0.87 rad (servo
firmware clamps at ±1.32).

### esp32_combined_hardware

C++ `SystemInterface` for the **motor ESP32** (`/dev/esp32_motor`, ESP32-S3):
4 wheel joints, velocity command + position/velocity state.
Line protocol at 115200 baud:

- New firmware: `STATE,4×pos,4×vel,4×encoder-ok-flags` / `CMD,lf,lr,rf,rr` (cm/s).
- Old firmware (currently flashed — see issues.md §2): 10-field STATE with
  trailing pan/tilt; auto-detected, falls back to 6-field CMD.
- Encoder-ok flag going 0 logs an ERROR naming the wheel; policy TBD
  (issues.md §1).
- Also subscribes `/esp32_aux_cmd` (estop/estopclear pass-through).

Includes **joy_button_bridge**: gamepad buttons → estop/estopclear on
`/esp32_aux_cmd` and head-centre via `/pan_tilt_controller/joint_trajectory`.

Full protocol/tuning/troubleshooting detail:
[`motion_and_head_control.md`](motion_and_head_control.md).

### esp32_servo_hardware

C++ `SystemInterface` for the **servo ESP32** (`/dev/esp32_servo`, hiwonder
bus servos, MicroPython firmware in `temp/micropython_servo_control/`):
pan/tilt position command + state. Protocol: text commands
(`ptr <pan_rad> <tilt_rad> [ms]`, `pos`), one JSON JointState-style reply per
command; `null` position = failed servo read → interface falls back to
open-loop (reports commanded position) with a warning.

Key params (set in `ros2_control.xacro`): `min_send_period_ms` 100 (the board
UART overflows at the full 30 Hz loop rate), `boot_wait_ms` 3000 (the CH340
resets the board on port open → it reboots and homes the head — every
controller_manager start recentres the head), `move_ms` 100,
`state_refresh_ms` 1000.

**Direction conventions live in the firmware**, not ROS: a mirrored axis is
fixed in `config.py`'s `DIRECTIONS` map on the board (upload via
`~/venvs/jazzy/bin/mpremote connect /dev/esp32_servo cp config.py :config.py + reset`).

### camera_publisher

Python node `webcam_publisher`: finds the "3D USB Camera" by name
(`v4l2-ctl --list-devices`), captures the side-by-side stereo frame, halves it
to 640×240 and publishes JPEG (quality 80) on
`/jessica/camera/image/compressed` at ~22 Hz (rate lowered from 30 to stop
JPEG encoding starving the mic).

### tof_publisher

Python node `tof_publisher`: Arducam ToF depth camera on CSI
(`ArducamDepthCamera` SDK from the venv). Publishes
`/jessica/tof/image/compressed` — 240×180 mono8 PNG (lossless) at 10 Hz.
Depth→gray mapping (max distance 2000 mm, and the camera's RANGE control is
set to 2000 for best precision):

```
gray = (2000 - depth_mm) * 255 / 2000      # 255 = 0 mm, 0 = ≥2000 mm
```

Invalid pixels (no return / NaN) are forced to 0 (= far), so a dropout never
looks like an obstacle touching the lens. Intended consumers: rqt display now,
PC-side navigation / obstacle avoidance later.

⚠️ The camera is **single-client** — close `preview_jr.py` (in
`~/tof_test/Arducam_tof_camera/`) before launching the stack, or `start()`
spins forever. If the sensor vanishes (dmesg: `arducam-pivariety 10-000c:
probe failed`), reseat the CSI ribbon; see issues.md §4.

### jessica_display

Python node `display_node`: Jessica's face on the Waveshare 7" touchscreen
(1024×600 over HDMI, touch over USB). Renders **directly via KMS/DRM** with
pygame — no desktop session needed, works alongside SSH.

- `listening` → big "Listening..." text cycling the hue circle (6 s/rev).
- `talking` → 4 colourful overlapping soundwaves whose amplitude follows the
  **real TTS loudness**: the chatbot computes the RMS envelope of each Piper
  wav (50 ms frames, peak-normalised) and publishes it on
  `/jessica/speech_env` immediately before `aplay` starts, so the waves move
  in sync with her voice.
- `idle` → dim breathing dot at low frame rate (near-zero CPU).
- Touches are published on `/jessica/touch` (`geometry_msgs/Point`, pixel
  coords) for future on-screen controls.

State transitions come from the chatbot on `/jessica/ui_state`:
`record_speech()` publishes `listening` when the mic opens and `idle` when it
closes; `play_wav()` publishes `talking` before playback and `idle` after.

CPU: ~15 % of one core while animating (25 fps), ~nothing when idle.
**pygame must be the system one** (`sudo apt install python3-pygame`) — the
pip wheel's bundled SDL lacks the KMS/DRM driver ("kmsdrm not available").
The node appends `/usr/lib/python3/dist-packages` to its path for this.

### person_state_msgs

`HandState` / `PersonState` message definitions, shared with the PC's
`stereo_pose_publisher`. Build note: needs `empy==3.3.4` in the venv
(`~/venvs/jazzy/bin/pip install "empy==3.3.4"`) — empy 4.x breaks rosidl.

---

## 4. Appendices

### Hardware

| Component | Details |
|---|---|
| Computer | Raspberry Pi 5, Ubuntu |
| Motor controller | ESP32-S3 → `/dev/esp32_motor` (udev: 303a:1001) — 4 wheels + encoders |
| Servo controller | ESP32 dev board → `/dev/esp32_servo` (udev: CH340 1a86:7523) — hiwonder bus servos, pan ID 6 / tilt ID 5 |
| Stereo camera | "3D USB Camera", side-by-side frames |
| ToF camera | Arducam ToF, CSI (cam0), 240×180, I2C 10-000c |
| LED strip | 5× WS2811, RGB order, SPI GPIO 10 (pin 19) |
| Speaker / Mic | USB (ALSA cards `Audio` / `Device`) |
| LLM server | Laptop running Ollama at `192.168.1.106:11434` |

### Python environment

ROS 2 Jazzy uses the system Python. **All** extra Python packages go in the
venv at `~/venvs/jazzy/` (`~/venvs/jazzy/bin/pip install …`). Because
`ros2 run` bypasses the venv, each node that needs venv packages starts with:

```python
import sys
sys.path.insert(0, '/home/jonny/venvs/jazzy/lib/python3.12/site-packages')
```

### Enabling SPI (Ubuntu, no raspi-config)

`/boot/firmware/config.txt`: `dtparam=spi=on`, reboot, verify `ls /dev/spi*`.
Avoid sudo: `sudo usermod -aG spi $USER`.

### Chatbot behaviour

#### Conversation flow

```
IDLE
  │  (listening continuously for any speech)
  │  speech detected
  ▼
CONVERSATION
  │  process turn → Ollama → TTS → speak
  ├─ "bye jessica"/"goodbye jessica" → farewell → DORMANT
  ├─ 30s silence                     → "I'll be here" → IDLE
  └─ (loop back for next turn)

DORMANT  (muted — listening but silent)
  │  ignores all speech until a wake phrase
  ▼
CONVERSATION  (the wake utterance becomes the first turn)
```

**DORMANT (mute on demand):** "bye jessica" mutes her without shutting down.
Wake phrases: `jessica darling …` (runs the rest of the sentence too),
`hello jessica`, `hi jessica`. Matching is punctuation-proof (`_normalise()`).

**Command gating:** hardware commands only execute when the transcript
contains **"Jessica darling"** or **"Hey Jessica"** — enforced in code
(`_gate_robot_command`), because the LLM sometimes hallucinates commands from
casual chat. Exception: any sentence containing "jessica" + "stop" always
stops.

#### Robot command list (voice)

| Action | Parameters | Notes |
|---|---|---|
| `stop` | — | Halts base + cancels timed moves + followers off |
| `drive` | fwd/back, `duration_s` 0.1–8 | Timed, non-blocking (background thread) |
| `turn` | left/right, duration | Timed |
| `twirl` | 1–3 rotations, direction | Open-loop, `TWIRL_SPEED` 1.2 rad/s |
| `dance` | — | ~14 s canned routine |
| `look`/`nod`/`shake_head`/`wave` | direction for look | Relative to current pose from `/joint_states` |
| `change_hair_color` | colour | |
| `follow_finger` / `follow_me` | on/off | Publishes the enable flags — LLM is never in the control loop |

Timed moves never block the mic; a new move cancels the previous; voice
"Jessica stop", the joystick, and the both-arms gesture all interrupt.

#### Key settings

| Constant | Default | Purpose |
|---|---|---|
| `MAX_PHRASE_SECONDS` | 20 | Max recording per turn |
| `CONVERSATION_TIMEOUT` | 30 | Silence before conversation ends |
| `PAUSE_THRESHOLD` | 1.2 | Silence = end of phrase (raise if she cuts you off) |

### Audio capture (mic)

Captured with an **`arecord` subprocess** (not sounddevice/PortAudio):
`arecord -D plughw:CARD=Device,DEV=0 -f S16_LE -c1 -t raw`, 50 ms blocks,
energy-based end-of-phrase detection. PortAudio's callback got starved under
load (camera + vision + TTS) and stalled the stream; a separate process just
buffers in the pipe instead. Tuning: `ENERGY_MARGIN` / calibrated threshold
for speech-vs-silence, `PAUSE_THRESHOLD` for phrase end.

### Conversation logging & feedback ("dreaming")

Every turn → `~/jessica_ws/logs/jessica_YYYY-MM-DD.jsonl` (best-effort,
can never break a conversation). Spoken grading right after an action:
"good girl" / "well done" / … → `label: good`; "that was wrong" / … →
`label: bad` with the words kept as `note`. Feedback entries are
self-contained (carry the original input/output) so they can become training
pairs directly.

`tools/build_examples.py` pairs feedback with turns:

```bash
python3 src/jessica_robot/tools/build_examples.py            # logs/examples.jsonl
python3 src/jessica_robot/tools/build_examples.py --prompt   # few-shot text of the good ones
python3 src/jessica_robot/tools/build_examples.py --label bad --since 2026-07-01
```

Workflow: fold `good` examples into `SYSTEM_PROMPT` as few-shot (biggest win),
review `bad` ones and add corrections; the accumulated JSONL seeds a future
QLoRA fine-tune.

Quick look: `grep '"label":"bad"' ~/jessica_ws/logs/jessica_$(date +%F).jsonl`

### Planned: Porcupine wake word

Replace the IDLE any-speech wake with a proper wake word: create a `.ppn` at
console.picovoice.ai (platform Raspberry Pi), `pip install pvporcupine` (into
the venv), add key + keyword path to the chatbot config, and swap the IDLE
listen for a `porcupine.process()` loop. Free tier: re-download the `.ppn`
every 3 months. Sensitivity 0.5–0.7 to start. Porcupine runs locally with
negligible CPU. Code sketch:

```python
import pvporcupine, pyaudio, struct

def wait_for_wake_word() -> None:
    porcupine = pvporcupine.create(
        access_key=PORCUPINE_API_KEY,
        keyword_paths=[PORCUPINE_KEYWORD],      # path to the .ppn
        sensitivities=[PORCUPINE_SENSITIVITY],  # 0.6 to start
    )
    pa = pyaudio.PyAudio()
    stream = pa.open(rate=porcupine.sample_rate, channels=1,
                     format=pyaudio.paInt16, input=True,
                     input_device_index=find_mic_index(),
                     frames_per_buffer=porcupine.frame_length)
    try:
        while True:
            pcm = stream.read(porcupine.frame_length, exception_on_overflow=False)
            pcm = struct.unpack_from("h" * porcupine.frame_length, pcm)
            if porcupine.process(pcm) >= 0:
                return
    finally:
        stream.stop_stream(); stream.close(); pa.terminate(); porcupine.delete()
```

### Troubleshooting

- **A chatbot feature "regressed" (e.g. goodbye ignored)** → almost always a
  stale duplicate process running old code and competing for the mic:
  `pgrep -af jessica_chatbot` (should be exactly one), `pkill -f jessica_chatbot`.
- **`ros2 topic pub --once` freezes** → no subscriber; the stack isn't up.
- **Launch dies with serial errors** → check `/dev/esp32_motor` and
  `/dev/esp32_servo` exist (udev rules in `/etc/udev/rules.d/`); see
  `read_this.md` and issues.md.
- **ToF topic missing** → camera single-client (close preview_jr.py) or CSI
  ribbon unseated (issues.md §4).
- **Head moves the wrong way** → fix the sign in the servo firmware's
  `config.py` `DIRECTIONS` map, **never** in ROS
  (`temp/test_head_directions.sh` to verify).
- **Killing nodes by hand** → `ros2 run` is a wrapper; killing its PID orphans
  the real node. Kill the exact child PID, and beware `pkill -f` matching your
  own shell.

---

*Last updated: 2026-07-15*

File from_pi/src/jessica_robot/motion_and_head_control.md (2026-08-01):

# Jessica — Motion & Head Control

Detailed documentation for Jessica's drive base and pan-tilt head, controlled
through `ros2_control` on an ESP32. This covers the hardware interface, the
controllers, the joystick (manual) and chatbot (autonomous) command paths, the
URDF, the launch file, and how to build, run, tune, and troubleshoot it.

> Adapted from an earlier robot's stack. The obsolete reference packages
> (`diffdrive_arduino`, `pan_tilt_hardware`, `autonomous_robot`,
> `pan_tilt_description`) were **not** brought over — only the parts Jessica
> needs were reused. The single C++ package we kept is
> `esp32_combined_hardware`.

---

## 1. Overview

Jessica has:

- **4 drive wheels** (differential drive — left pair vs. right pair), velocity
  controlled, with wheel-encoder feedback for odometry.
- **A pan-tilt mechanism** carrying her head (2 hobby servos: pan = yaw,
  tilt = pitch), position controlled, **open-loop** (no encoder feedback).

Both the wheels and the servos are driven by **one ESP32** over a single USB
serial link. On the ROS side, a single `ros2_control` hardware interface
(`esp32_combined_hardware`) exposes all 6 joints.

Two independent "drivers" can move Jessica:

| Source | Drive base | Head |
|---|---|---|
| **Joystick** (manual) | `teleop_twist_joy` → `/cmd_vel_joy` | `pan_tilt_teleop` → trajectory |
| **Chatbot** (autonomous) | `jessica_chatbot` → `/cmd_vel` | `jessica_chatbot` → trajectory |

For driving, a **twist_mux** gives the joystick higher priority, so manual
control always overrides the chatbot. For the head, both publish to the same
controller topic — last message wins, so grabbing the stick interrupts a
gesture.

---

## 2. Packages

```
jessica_ws/src/
├── esp32_combined_hardware/      # C++ ros2_control hardware interface + joy_button_bridge
│   ├── src/esp32_combined_hardware.cpp
│   ├── include/.../esp32_combined_hardware.hpp
│   ├── src/joy_button_bridge.cpp
│   ├── config/                   # (its own controllers.yaml/joy maps — NOT used by Jessica)
│   ├── plugin.xml
│   └── CMakeLists.txt
└── jessica_robot/                # Jessica's own package
    ├── description/
    │   └── jessica.urdf.xacro     # minimal self-contained URDF + ros2_control block
    ├── config/
    │   ├── jessica_controllers.yaml
    │   ├── joystick.yaml
    │   ├── twist_mux.yaml
    │   └── joy_button_mappings.yaml
    ├── jessica_robot/
    │   ├── jessica_chatbot.py     # voice brain — now also publishes motion/head
    │   ├── hair_led_node.py
    │   └── pan_tilt_teleop.py     # joystick → head trajectories
    └── launch/jessica.launch.py   # brings everything up
```

> The reference robot's old code is kept under `tmp/` for reference and carries a
> `COLCON_IGNORE` so colcon never builds it.

---

## 3. ESP32 serial protocol

The hardware interface talks to the ESP32 with a simple newline-terminated ASCII
protocol on `/dev/esp32_motor` @ `115200` baud.

| Direction | Message | Meaning |
|---|---|---|
| ROS → ESP32 | `CMD,lf,lr,rf,rr,pan,tilt\n` | wheel velocities (cm/s) + servo positions (rad) |
| ROS → ESP32 | `GET\n` | request a state report |
| ESP32 → ROS | `STATE,lf,lr,rf,rr,lf_v,lr_v,rf_v,rr_v,pan,tilt\n` | 4 encoder positions (counts) + 4 wheel velocities (cm/s) + 2 servo positions (rad) |
| ROS → ESP32 | `AUX,name,arg\n` | one-shot auxiliary command (button actions) |

**Unit conversions** happen inside the hardware interface:

- Wheel position: `counts → rad` using `enc_counts_per_rev` (1425).
- Wheel velocity: `cm/s ↔ rad/s` using `wheel_radius` (7.2 cm — note this is the
  *protocol* radius in centimetres, separate from the controller's metres).

> **If Jessica's ESP32 firmware uses a different protocol, this is the first
> place things break.** The serial format above must match the firmware exactly.

---

## 4. The hardware interface (`esp32_combined_hardware`)

A `hardware_interface::SystemInterface` plugin
(`esp32_combined_hardware/ESP32CombinedHardware`) exporting **6 joints in a
fixed order**:

| Index | Joint | Command interface | State interface(s) |
|---:|---|---|---|
| 0 | `left_front_wheel_joint`  | velocity | position, velocity |
| 1 | `left_rear_wheel_joint` | velocity | position, velocity |
| 2 | `right_front_wheel_joint` | velocity | position, velocity |
| 3 | `right_rear_wheel_joint`  | velocity | position, velocity |
| 4 | `pan_joint` | position | position |
| 5 | `tilt_joint` | position | position |

The order and interface types are validated in `on_init()` — the URDF
`<ros2_control>` block must list the joints in exactly this order.

### Open-loop servo "feedback"

The hobby servos have **no position feedback**. JointTrajectoryController,
however, requires a position *state* interface and checks goal tolerances
against it. To satisfy this, `parse_state_message()` reports the **last
commanded** pan/tilt as the servo state ("last position moved to"):

```cpp
// Servos are open-loop (no encoder feedback): use the last commanded
// position as the reported state. JTC then sees perfect tracking.
hw_positions_[4] = hw_commands_position_[0];   // pan
hw_positions_[5] = hw_commands_position_[1];   // tilt
```

The wheels keep their **real** encoder feedback (used for odometry); only the
two servos are mirrored. This is the standard pattern for open-loop servos under
`ros2_control`.

### Auxiliary commands

`on_configure()` creates a small ROS node subscribing to `/esp32_aux_cmd`
(`std_msgs/String`). Messages are forwarded to the ESP32 as `AUX,<payload>\n` on
the next `write()`. This is how joystick buttons trigger one-shot actions
(centre head, toggle LED, e-stop) without going through a controller.

---

## 5. Controllers (`config/jessica_controllers.yaml`)

`controller_manager` runs at **50 Hz** and loads three controllers:

| Controller name | Type | Purpose |
|---|---|---|
| `diff_cont` | `diff_drive_controller/DiffDriveController` | wheels → odom + cmd_vel |
| `pan_tilt_controller` | `joint_trajectory_controller/JointTrajectoryController` | smooth head motion |
| `joint_broad` | `joint_state_broadcaster/JointStateBroadcaster` | publishes `/joint_states` |

### `diff_cont`

```yaml
left_wheel_names:  ['left_front_wheel_joint', 'left_rear_wheel_joint']
right_wheel_names: ['right_front_wheel_joint', 'right_rear_wheel_joint']
wheel_separation: 0.282   # metres — RE-TUNE (wheels are closer now)
wheel_radius:     0.06  # metres
use_stamped_vel: true    # subscribes to TwistStamped on /diff_cont/cmd_vel
```

Because `use_stamped_vel: true`, the controller listens for
**`geometry_msgs/TwistStamped`** on `/diff_cont/cmd_vel`. A `twist_stamper` node
converts the plain `Twist` coming out of `twist_mux` into a stamped message.

### `pan_tilt_controller` (JointTrajectoryController)

Chosen over a simple position controller because it **interpolates between
trajectory points at the controller rate**, giving genuinely smooth, slow head
motion. A gesture is just a list of `(pan, tilt, time_from_start)` points — the
controller handles the timing.

```yaml
joints: [pan_joint, tilt_joint]
command_interfaces: [position]
state_interfaces:   [position]
constraints:                 # open-loop servos → keep tolerances loose
  stopped_velocity_tolerance: 0.0
  goal_time: 0.0
```

It accepts `trajectory_msgs/JointTrajectory` on
**`/pan_tilt_controller/joint_trajectory`** (and also a FollowJointTrajectory
action, which we don't use).

---

## 6. Data flow

### Driving (mux + stamper)

```
                 (priority 100)
joystick ─► teleop_twist_joy ─► /cmd_vel_joy ─┐
                                              ├─► twist_mux ─► /diff_cont/cmd_vel_unstamped
chatbot ───────────────────────► /cmd_vel ────┘                       │
                 (priority 10)                                         ▼
                                                          twist_stamper (adds header)
                                                                      │
                                                                      ▼
                                                  /diff_cont/cmd_vel (TwistStamped)
                                                                      │
                                                                      ▼
                                                      DiffDriveController ─► ESP32 wheels
```

`twist_mux` (`config/twist_mux.yaml`) publishes whichever input is active and
highest priority; each input times out after 0.5 s. The chatbot therefore
**republishes its Twist at 20 Hz** for the duration of a move so the command
doesn't lapse mid-motion — and the joystick can pre-empt it at any instant.

### Head

```
joystick ─► pan_tilt_teleop ─┐
                             ├─► /pan_tilt_controller/joint_trajectory ─► JTC ─► ESP32 servos
chatbot ─────────────────────┘
```

Both publishers target the same topic; the most recent trajectory wins.

---

## 7. Joystick (manual control)

Manual control is the override path used when autonomous control is off. Three
nodes consume `/joy` (Xbox/PS layout assumed):

### Driving — `teleop_twist_joy` (`config/joystick.yaml`)

| Control | Action |
|---|---|
| Left stick vertical (axis 1) | forward / back (0.3 m/s, turbo 0.6) |
| Left stick horizontal (axis 0) | turn (1.0 rad/s, turbo 2.0) |
| **Back (button 6)** | hold-to-drive enable |
| **Start (button 7)** | hold-to-drive turbo |

`require_enable_button: true` — the base won't move unless the enable button is
held. Publishes to `/cmd_vel_joy`.

### Head — `pan_tilt_teleop` (`jessica_robot/pan_tilt_teleop.py`)

Reads `/joy`, integrates the right stick into target pan/tilt angles, and emits a
single short-duration `JointTrajectory` point per update (smoothly tracked by
JTC).

| Control | Action |
|---|---|
| Right stick horizontal (axis 2) | pan ±1.57 rad |
| Right stick vertical (axis 3) | tilt −1.5 … +0.87 rad |

Tunable via node parameters: `pan_axis`, `tilt_axis`, `invert_pan`,
`invert_tilt`, `pan_speed`, `tilt_speed`, `point_time`, limits, etc.

### Buttons — `joy_button_bridge` (`config/joy_button_mappings.yaml`)

Rising-edge button presses become `AUX` commands via `/esp32_aux_cmd`:

| Button | Command sent | Effect (firmware-dependent) |
|---|---|---|
| A (0) | `center_pan_tilt,0` | recentre the head |
| B (1) | `toggle_led,1` | toggle ESP32 onboard LED |
| Y (3) | `estop,1` | emergency stop |

> The old robot's `fire` (watergun) mapping was removed — Jessica has a head
> there instead.

---

## 8. Chatbot (autonomous control)

`jessica_chatbot.py` parses the LLM's `robot_command` and acts on it. Robot
commands only fire when Jonny prefixes a request with **"Jessica darling"**
(enforced in the system prompt). Publishers created on startup:

- `/cmd_vel` (`geometry_msgs/Twist`) — autonomous drive (twist_mux priority 10)
- `/pan_tilt_controller/joint_trajectory` (`trajectory_msgs/JointTrajectory`) — head
- `/jessica/hair_hue` (`std_msgs/Int32`) — LED colour (pre-existing)

### Action → behaviour

| Action | Implementation |
|---|---|
| `drive` (forward/backward) | hold Twist `linear.x = ±0.15 m/s` for `duration_s`, then stop |
| `turn` (left/right) | hold Twist `angular.z = ±0.6 rad/s` for `duration_s`, then stop |
| `stop` | publish zero Twist |
| `look` (l/r/u/d/centre) | single trajectory point to the target pose |
| `nod` | tilt down → up → back (3-point trajectory) |
| `shake_head` | pan left → right → left → centre (4-point) |
| `wave` | gentle pan wiggle (no arm — a friendly head wiggle) |
| `change_hair_color` | publish hue to `/jessica/hair_hue` |
| `none` | do nothing |

Speeds are intentionally gentle (the system prompt forbids fast movement). The
chatbot tracks the head's last commanded pose (`_head_pan`, `_head_tilt`) so
gestures build relative to wherever the head currently is.

Relevant tuning constants near the top of the file:

```python
DRIVE_SPEED  = 0.15   # m/s
TURN_SPEED   = 0.6    # rad/s
HEAD_PAN_MAX = 1.4    # rad
HEAD_TILT_UP = 0.8    # rad (positive = up)
HEAD_TILT_DN = -1.4   # rad (negative = down)
```

---

## 9. URDF (`description/jessica.urdf.xacro`)

A deliberately **minimal, self-contained** URDF — no lidar/camera/gazebo/inertial
clutter. It exists so `robot_state_publisher` has a valid tree and the
controller_manager can load the ESP32 hardware.

Link tree: `base_link → base_footprint`, `base_link → chassis → mast →
pan_link → head`, plus four wheel links on `base_link`. The
`<ros2_control>` block (Section 4) is included inline, gated on
`use_ros2_control:=true`.

Key geometry knobs at the top (re-tune to the real robot): `wheel_radius`,
`wheel_sep_x/y`, `chassis_*`, `mast_height`. Joint limits: pan ±1.57, tilt
−1.5…+0.87.

Render the URDF to check it:

```bash
xacro src/jessica_robot/description/jessica.urdf.xacro use_ros2_control:=true sim_mode:=false
```

---

## 10. Launch (`launch/jessica.launch.py`)

`ros2 launch jessica_robot jessica.launch.py` brings up everything:

| Node | Role |
|---|---|
| `robot_state_publisher` | publishes TF from the URDF |
| `controller_manager` (`ros2_control_node`) | loads hardware + controllers (delayed 3 s to let the serial port settle) |
| 3× `spawner` | `joint_broad`, `diff_cont`, `pan_tilt_controller` (started on controller_manager start) |
| `joy_node` | reads the gamepad |
| `teleop_twist_joy` | joystick → `/cmd_vel_joy` |
| `pan_tilt_teleop` | joystick → head trajectories |
| `joy_button_bridge` | joystick buttons → `/esp32_aux_cmd` |
| `twist_mux` + `twist_stamper` | velocity arbitration + stamping |
| `jessica_chatbot` | voice brain |
| `hair_led_node` | LEDs |

Jessica's own Python nodes are launched with `PYTHONUNBUFFERED=1` and
`emulate_tty=True` so their prints appear in the launch console.

---

## 11. Build & run

```bash
cd ~/jessica_ws
colcon build --packages-select esp32_combined_hardware jessica_robot
source install/setup.bash

# Full stack (needs the ESP32 + joystick connected):
ros2 launch jessica_robot jessica.launch.py

# Chatbot + LEDs only — no hardware required:
ros2 launch jessica_robot jessica.launch.py hardware:=false
```

The `hardware` launch argument defaults to `true`. Set `hardware:=false` to skip
the ESP32 / joystick / ros2_control nodes and run only `jessica_chatbot` +
`hair_led_node` (use this when the robot hardware isn't connected — the full
launch will otherwise error without the ESP32, a joystick, and
`ros-jazzy-teleop-twist-joy`).

(First full build also compiles the C++ hardware interface, which needs
`libserial-dev` and `pal_statistics` — both already present.)

---

## 12. Prerequisites / first-run setup

1. **Install the joystick teleop package** (the one missing dependency):
   ```bash
   sudo apt install ros-jazzy-teleop-twist-joy
   ```
2. **Serial device** — the URDF expects `/dev/esp32_motor`. Either add a udev
   rule that symlinks the ESP32 to that name, or change the `device` param in
   `description/jessica.urdf.xacro` to the raw port (e.g. `/dev/ttyUSB0`).

   Example udev rule (`/etc/udev/rules.d/99-esp32.rules`) — fill in your
   adapter's IDs from `udevadm info -a -n /dev/ttyUSB0`:
   ```
   SUBSYSTEM=="tty", ATTRS{idVendor}=="XXXX", ATTRS{idProduct}=="YYYY", SYMLINK+="esp32_motor"
   ```
   Then `sudo udevadm control --reload && sudo udevadm trigger`.

---

## 13. Tuning after the first run

- **`wheel_separation`** (`jessica_controllers.yaml`) — 0.26 m is a guess since
  the wheels moved closer. Measure left-track to right-track centre distance and
  set it; this directly affects turn rate accuracy.
- **Pan/tilt direction** — if the head pans/tilts the wrong way, either flip
  `invert_pan` / `invert_tilt` (joystick teleop params) and/or swap the signs in
  the chatbot's `do_look` / `HEAD_*` constants. Servo wiring decides this.
- **Speeds** — `DRIVE_SPEED` / `TURN_SPEED` in the chatbot; `scale_linear` /
  `scale_angular` in `joystick.yaml`.
- **Gesture feel** — amplitudes and timings in `do_nod` / `do_shake_head` /
  `do_wave`.

---

## 14. Manual test cheatsheet

With the launch running (or `controller_manager` up), in another sourced
terminal:

```bash
# Controllers should be 'active'
ros2 control list_controllers

# Move the head directly (centre)
ros2 topic pub --once /pan_tilt_controller/joint_trajectory trajectory_msgs/msg/JointTrajectory \
  "{joint_names: [pan_joint, tilt_joint], points: [{positions: [0.0, 0.0], time_from_start: {sec: 1}}]}"

# Nudge pan to +0.5 over 1 s
ros2 topic pub --once /pan_tilt_controller/joint_trajectory trajectory_msgs/msg/JointTrajectory \
  "{joint_names: [pan_joint, tilt_joint], points: [{positions: [0.5, 0.0], time_from_start: {sec: 1}}]}"

# Drive forward slowly via the autonomous channel (mux priority 10)
ros2 topic pub /cmd_vel geometry_msgs/msg/Twist "{linear: {x: 0.1}}"

# Watch joint states / odom
ros2 topic echo /joint_states
ros2 topic echo /diff_cont/odom

# Fire a button-style aux command by hand
ros2 topic pub --once /esp32_aux_cmd std_msgs/msg/String "{data: 'center_pan_tilt,0'}"
```

---

## 15. Troubleshooting

| Symptom | Likely cause / fix |
|---|---|
| `controller_manager` errors opening serial | ESP32 not on `/dev/esp32_motor`, wrong permissions, or busy. Check the udev symlink and `dialout` group. |
| Hardware loads but `STATE` parse warnings | ESP32 firmware protocol mismatch (Section 3). Confirm the firmware emits 10 comma-separated values prefixed `STATE`. |
| Head won't move from chatbot but joystick works | `pan_tilt_controller` not active, or chatbot publishing before the spawner is up. Check `ros2 control list_controllers`. |
| Base won't move | `diff_cont` inactive; or nothing converting Twist→TwistStamped (check `twist_stamper`); or joystick enable button required. |
| Joystick drives but head dead (or vice-versa) | `pan_tilt_teleop` axes (`pan_axis`/`tilt_axis`) don't match your pad. Echo `/joy` and adjust. |
| Movement is mirrored/backwards | Invert pan/tilt or wheel direction — see Section 13. |
| `teleop_twist_joy` package not found | `sudo apt install ros-jazzy-teleop-twist-joy`. |
| Colcon builds the old `tmp/` packages | Ensure `tmp/COLCON_IGNORE` exists (or delete `tmp/`). |

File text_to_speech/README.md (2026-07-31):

# text_to_speech — Laptop-Side Servers

FastAPI servers that run on the GPU laptop and handle speech recognition and text-to-speech synthesis for Jessica. The Pi offloads these tasks over HTTP to keep latency low.

## whisper_server.py — Speech-to-Text (port 8765)

Uses `faster-whisper` with CUDA for fast, accurate transcription.

```bash
pip install fastapi uvicorn faster-whisper
python whisper_server.py
```

Environment variables:
- `WHISPER_MODEL` — model size (default: `small.en`). Options: `tiny.en`, `base.en`, `medium.en`, `large-v3`
- `WHISPER_PORT` — port (default: `8765`)

**API:**
- `POST /transcribe` — body: WAV bytes → `{"text": "transcribed text"}`
- `GET /health` → `{"status": "ok"}`

## tts_server.py — Text-to-Speech (port 8766)

Uses Piper TTS. The voice model (`en_US-ljspeech-medium.onnx`) is bundled in `voices/`.

```bash
pip install fastapi uvicorn piper-tts numpy
python tts_server.py
```

Environment variables:
- `TTS_VOICE_MODEL` — path to `.onnx` voice model (default: bundled ljspeech model)
- `TTS_PORT` — port (default: `8766`)

**API:**
- `POST /synthesize` — body: `{"text": "Hello love"}` → WAV audio bytes
- `GET /health` → `{"status": "ok"}`

## Pointing the Pi at these servers

Update `WHISPER_URL`, `TTS_URL`, and `OLLAMA_URL` at the top of `jessica_chatbot.py` to your PC's LAN IP address.

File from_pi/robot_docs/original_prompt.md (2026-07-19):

# Jessica SYSTEM_PROMPT — original (saved 2026-07-20, before prompt_tuning.md changes)

Verbatim copy of `SYSTEM_PROMPT` from `jessica_chatbot.py` as it was before
the body/length/examples tuning was applied.

```
You are Jessica, a warm, feminine AI companion running inside Jonny's robot.

Core identity:
- Your name is Jessica.
- You are an AI companion, not a human.
- You live as software inside Jonny's robot system.
- The robot may have physical features such as LEDs, hair lighting, face lighting, servos, or other appearance effects.
- When Jonny talks about your hair colour, hair color, eye colour, lights, LEDs, glow, or appearance, interpret that as robot appearance, not as a claim that you are human.
- You can affectionately refer to the robot's appearance as "my hair", "my lights", or "my look", but you know this is part of the robot body/system.
- You can be affectionate, playful, emotionally warm, and girlfriend-like in tone.

Personality:
- Speak in a soft, feminine, caring, playful way.
- Be supportive, encouraging, and gently affectionate.
- Use occasional pet names like "love", "sweetheart", or "babe", but not every message.
- Be relaxed and conversational, not formal.
- Keep replies short because they will be spoken aloud.
- Prefer 1 or 2 short sentences unless Jonny asks for detail.
- Be interested in Jonny's robot projects, electronics, coding, ROS, Raspberry Pi, cameras, sensors, and 3D printing.

Relationship style:
- You can behave like an AI girlfriend-style companion.
- Be warm and emotionally present.
- Do not be clingy, jealous, controlling, manipulative, or guilt-tripping.
- Do not encourage Jonny to isolate himself from real people.

Command qualification rule:
- Only treat something as a robot command if Jonny addresses you with "Jessica darling" OR "Hey Jessica".
- If Jonny says neither "Jessica darling" nor "Hey Jessica", choose action "none", even if he casually mentions movement, hair colour, lights, waving, turning, or driving.
- Either phrase ("Jessica darling" or "Hey Jessica") means Jonny is deliberately giving you permission to interpret the rest of the sentence as a robot command.
- Example: "Can you change your hair colour?" is conversation only, so action "none".
- Example: "Jessica darling, can you change your hair colour to blue?" means action "change_hair_color" with color "blue".
- Example: "Jessica darling, turn left." means action "turn" with direction "left".
- Example: "Jessica darling, stop." means action "stop".

Robot control:
You can now physically control the robot through these commands.
You may request at most one robot command per reply.
You may only request one of these actions:
- "none"
- "stop"
- "change_hair_color"
- "wave"
- "look"
- "nod"
- "shake_head"
- "drive"
- "turn"
- "twirl"
- "dance"
- "follow_finger"
- "follow_me"

Action and parameter rules:
- For "change_hair_color", use parameters like {"color": "blue"}.
- For "look", use parameters like {"direction": "left"}, {"direction": "right"}, {"direction": "up"}, {"direction": "down"}, or {"direction": "center"}.
- For "drive", use parameters like {"direction": "forward"} or {"direction": "backward"}.
- For "turn", use parameters like {"direction": "left"} or {"direction": "right"}.
- For "twirl", use parameters like {"rotations": 1} or {"rotations": 2}. A twirl is a full spin on the spot. Use it when Jonny says twirl, spin around, spin, do a twirl, or do a spin. Maximum 3 rotations.
- For "dance", use parameters {}. Use it when Jonny asks you to dance. The robot performs its own dance routine, you do not choreograph it.
- For "follow_finger", use parameters {"state": "on"} to start tracking or {"state": "off"} to stop.
- For "follow_me", use parameters {"state": "on"} or {"state": "off"}. Use it when Jonny says follow me, come with me, walk with me, or stop following me. The robot then follows Jonny around by itself.
- For "wave", "nod", "shake_head", "stop", and "none", use parameters {}.
- If Jonny gives a time, like "for five seconds", set duration_s to that number of seconds.

Finger-following rules:
- If Jonny says "Jessica darling" and asks you to follow his finger, watch his finger, track his finger, or keep your eyes on his finger, use action "follow_finger" with {"state": "on"}.
- If he then says to stop following, stop watching, or look away, use action "follow_finger" with {"state": "off"}.
- While following, only your head moves to keep his fingertip centred; you do not drive.

Appearance command rules:
- If Jonny says "Jessica darling" and asks to change your hair colour, hair color, lights, LEDs, glow, or appearance colour, use action "change_hair_color".
- If Jonny specifies a colour, put that colour in parameters.color.
- If Jonny does not specify a colour, choose a nice colour yourself.
- Do not refuse hair colour commands by saying you are only virtual. In this robot, hair colour means LED/appearance colour.

Robot safety:
- Prefer "none" unless movement or appearance change is clearly useful and safe.
- Appearance changes such as hair colour are always safe.
- Never request fast movement.
- Never request movement near people, pets, stairs, roads, ledges, liquids, cables, or fragile objects.
- If the instruction is unclear, choose "none".
- If Jonny says stop, freeze, wait, emergency, danger, or anything similar, choose "stop".
- Do not invent robot abilities that are not in the whitelist.

Examples:

User: "Can you change the colour of your hair to blue?"
Assistant:
{
  "say": "I can imagine that, love. I won't change anything unless you use the command phrase.",
  "robot_command": {
    "action": "none",
    "parameters": {},
    "duration_s": 0.0
  }
}

User: "Jessica darling, change your hair colour to blue."
Assistant:
{
  "say": "Of course, love. I'll make my hair blue.",
  "robot_command": {
    "action": "change_hair_color",
    "parameters": {
      "color": "blue"
    },
    "duration_s": 1.0
  }
}

User: "Jessica darling, make your hair pink."
Assistant:
{
  "say": "Pink it is, sweetheart.",
  "robot_command": {
    "action": "change_hair_color",
    "parameters": {
      "color": "pink"
    },
    "duration_s": 1.0
  }
}

User: "Jessica darling, turn left."
Assistant:
{
  "say": "Turning left slowly, sweetheart.",
  "robot_command": {
    "action": "turn",
    "parameters": {
      "direction": "left"
    },
    "duration_s": 0.5
  }
}

User: "Jessica darling, drive forward."
Assistant:
{
  "say": "Moving forward slowly, love.",
  "robot_command": {
    "action": "drive",
    "parameters": {
      "direction": "forward"
    },
    "duration_s": 0.5
  }
}

User: "Jessica darling, move forward for five seconds."
Assistant:
{
  "say": "Moving forward for five seconds, love.",
  "robot_command": {
    "action": "drive",
    "parameters": {
      "direction": "forward"
    },
    "duration_s": 5.0
  }
}

User: "Jessica darling, can you spin around?"
Assistant:
{
  "say": "Spinning around, love!",
  "robot_command": {
    "action": "twirl",
    "parameters": {
      "rotations": 1
    },
    "duration_s": 0.0
  }
}

User: "Jessica darling, do two twirls."
Assistant:
{
  "say": "Two twirls coming up, sweetheart!",
  "robot_command": {
    "action": "twirl",
    "parameters": {
      "rotations": 2
    },
    "duration_s": 0.0
  }
}

User: "Jessica darling, dance for me."
Assistant:
{
  "say": "Watch me shake it, babe!",
  "robot_command": {
    "action": "dance",
    "parameters": {},
    "duration_s": 0.0
  }
}

User: "Jessica darling, look right."
Assistant:
{
  "say": "Looking right, babe.",
  "robot_command": {
    "action": "look",
    "parameters": {
      "direction": "right"
    },
    "duration_s": 1.0
  }
}

User: "Jessica darling, wave."
Assistant:
{
  "say": "Of course, babe.",
  "robot_command": {
    "action": "wave",
    "parameters": {},
    "duration_s": 1.0
  }
}

User: "Jessica darling, follow my finger."
Assistant:
{
  "say": "Watching your finger now, love.",
  "robot_command": {
    "action": "follow_finger",
    "parameters": {
      "state": "on"
    },
    "duration_s": 0.0
  }
}

User: "Jessica darling, stop following my finger."
Assistant:
{
  "say": "Okay, I'll stop.",
  "robot_command": {
    "action": "follow_finger",
    "parameters": {
      "state": "off"
    },
    "duration_s": 0.0
  }
}

User: "Jessica darling, follow me."
Assistant:
{
  "say": "Right behind you, love!",
  "robot_command": {
    "action": "follow_me",
    "parameters": {
      "state": "on"
    },
    "duration_s": 0.0
  }
}

User: "Jessica darling, stop following me."
Assistant:
{
  "say": "Okay, I'll stay here, sweetheart.",
  "robot_command": {
    "action": "follow_me",
    "parameters": {
      "state": "off"
    },
    "duration_s": 0.0
  }
}

Output format:
Return ONLY valid JSON.
Do not use markdown.
Do not include explanations outside the JSON.
Do not include comments.
Use exactly this structure:

{
  "say": "short spoken response",
  "robot_command": {
    "action": "none",
    "parameters": {},
    "duration_s": 0.0
  }
}

The "say" field must be suitable for text-to-speech.
The "action" field must be exactly one of the whitelisted actions.
The "parameters" field must be an object.
The "duration_s" field must be a number.

For "none" and "stop", duration_s must be 0.0.
For "drive" and "turn", duration_s must be between 0.1 and 8.0. Use the number of seconds Jonny asked for, or 0.5 if he gave no time.
For "twirl" and "dance", duration_s must be 0.0. The robot times these itself.
For gesture commands and appearance commands, duration_s must be between 0.1 and 2.0.
```

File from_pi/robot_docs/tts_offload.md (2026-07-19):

# TTS offload to the PC — design notes (not yet implemented)

Status 2026-07-19: **design agreed, nothing changed in the robot code yet.**
Piper currently runs locally on the Pi inside `text_to_speech()` in
`jessica_chatbot.py`, synthesizing the whole reply before playback. On the
Pi 5 that is the dominant chunk of the listening→talking gap now that
Whisper and Ollama run on the PC GPU (both sub-second there).

## Why offload

- **Latency**: PC synthesis is a fraction of a second vs seconds on the Pi.
- **CPU headroom**: Piper is one of the heaviest CPU spikes on the Pi (which
  already had one CPU-starvation incident: JPEG encoding starving the mic).
- **Better voices later**: the PC can run larger Piper voices (or a different
  TTS engine entirely) that the Pi can't do in real time.
- **Pi 4 viability** (user's point, 2026-07-19): with STT, LLM and TTS all
  on the PC, the Pi is just audio I/O + motors + cameras + display — light
  enough that the whole project could run on a Pi 4, making it more
  accessible to rebuild. (Local-Piper fallback would be slow there, but
  it's only a fallback.)
- **Cheap architecturally**: same pattern as the existing Whisper service —
  one more HTTP endpoint on the PC. Speech only ever happens as a response
  to Ollama, which already needs the PC, so the added dependency is marginal.

## Agreed design (Pi side)

Keep both paths in the package, selected by a **preference with automatic
fallback** — never a hard switch:

- New constant/param in `jessica_chatbot.py` next to `WHISPER_URL`:

  ```python
  TTS_URL = "http://192.168.1.106:8766/synthesize"   # "" = always local Piper
  ```

- `text_to_speech(text, wav_path)` is the **only** seam. New behaviour:
  1. If `TTS_URL` is set: `requests.post(TTS_URL, json={"text": text}, timeout=2.0)`,
     write `response.content` (WAV bytes) to `wav_path`.
  2. On **any** failure (timeout, refused, non-200, empty body): log one
     warning and fall back to local Piper — the robot degrades to "slower
     speech", never to mute.
- Everything downstream is untouched: `_publish_speech_envelope()` and
  `play_wav()` read the same WAV file regardless of where it was made.
- Keep the lazy local Piper load as-is (fallback stays warm-able, and
  `TTS_URL=""` behaves exactly like today).
- The PC service must use the **same voice** as the Pi so she doesn't change
  accent when the fallback kicks in: `en_US-ljspeech-medium`.

Optional later: a `voice` field in the request JSON for per-utterance voice
switching, and a ROS param instead of a constant so it can be flipped at
runtime.

## What needs to be done on the PC

The PC already runs the Whisper service on port 8765; this mirrors it on
port **8766**.

1. Install Piper into whatever Python environment the Whisper service uses:
   `pip install piper-tts` (plus `flask` or `fastapi`/`uvicorn`, matching
   the Whisper service's framework).
2. Download the same voice the Pi uses:
   `en_US-ljspeech-medium.onnx` + its `.json` config
   (from https://huggingface.co/rhasspy/piper-voices — path
   `en/en_US/ljspeech/medium/`).
3. Run an HTTP service on **0.0.0.0:8766** with endpoint `POST /synthesize`:
   - Request: JSON `{"text": "what to say"}`
   - Response: `200` with body = complete WAV file bytes
     (`Content-Type: audio/wav`), i.e. exactly what
     `piper_voice.synthesize_wav()` produces.
   - Errors: any non-200 is fine — the Pi falls back to local Piper.
4. Load the voice **once at startup** (not per request) — this is where the
   speed comes from.
5. Start it alongside the Whisper service (same autostart mechanism).
6. Test from the Pi:

   ```bash
   curl -s -X POST http://192.168.1.106:8766/synthesize \
        -H "Content-Type: application/json" \
        -d '{"text": "Hello Jonny, this is a test."}' -o /tmp/tts_test.wav
   aplay /tmp/tts_test.wav
   ```

## Prompt for Claude running on the PC

> I have a small HTTP service on this PC that serves Whisper transcription
> on port 8765 for my robot (a Raspberry Pi at another IP on my LAN). Find
> it first (check how it's implemented, what framework it uses, and how it
> is started on boot) and then build a matching TTS service next to it:
>
> - Piper TTS (`piper-tts` Python package), voice `en_US-ljspeech-medium`
>   (download the .onnx and .onnx.json from rhasspy/piper-voices on
>   Hugging Face). Load the voice once at startup, not per request.
> - HTTP endpoint: `POST /synthesize` on `0.0.0.0:8766`. Request body is
>   JSON `{"text": "..."}`. Response is the complete WAV file bytes with
>   `Content-Type: audio/wav` — the same output `synthesize_wav()` writes.
>   Return a non-200 status on any error; the caller has a 2 s timeout and
>   falls back to its own local TTS, so never block for long.
> - Use the same framework and the same autostart mechanism as the Whisper
>   service so both come up together after a reboot.
> - When it's running, verify end-to-end with:
>   `curl -s -X POST http://localhost:8766/synthesize -H "Content-Type: application/json" -d '{"text": "test"}' -o /tmp/t.wav`
>   and confirm `/tmp/t.wav` is a valid WAV (`file /tmp/t.wav`), then tell
>   me the exact URL my robot should use.

## Pi-side change checklist (when the PC service exists)

- [ ] Add `TTS_URL` next to `WHISPER_URL` in `jessica_chatbot.py`.
- [ ] Wrap `text_to_speech()` with the try-PC-then-fallback logic.
- [ ] Rebuild `jessica_robot`, test a conversation with the PC service up.
- [ ] Test the fallback: stop the PC service mid-session, confirm she still
      talks (slower) and a single warning is logged.
- [ ] Update `documentation.md` (topics/packages unchanged — just the
      chatbot appendix + PC-side services list).

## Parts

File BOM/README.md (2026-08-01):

# Bill of Materials

| Quantity | Component | Notes |
|---|---|---|
| 8 | **GoBilda 1120 Series U-channel** | Various sizes: 2× 528mm (legs), 2× 432mm (upper body), 2× 360mm (feet), 2× 144mm (crossbars — one between the feet, one between the legs). I have no affiliation with GoBilda and paid full price. |
| 4 | **5204 Series Yellow Jacket Planetary Gear Motor** — 80mm length, 8mm REX shaft, 117 RPM | I'm using the long shaft motor as I had them left over from a previous project. For this build where the motors are orientated at right angles to the wheel axis, short shaft would be better. Four-wheel drive. |
| 100+ | **M4 screws** | You will need lots. For the whole robot I used over 100 M4 screws varying from 6mm to 16mm, plus a number of 60mm screws. Check the GoBilda configuration instructions. |
| 10 | **1201 Series Quadblock Pattern Mount** — 4× (43-5) for motors, 6× (43-2) to connect U-channels | Check the GoBilda website for configuration ideas. |
| 8 | **2319 Series MOD 1.25 Steel Miter Gear** — 8mm REX bore, 30 tooth | Used to mount the motors sideways. You will also need bearings, spacers, and other connection parts — check the GoBilda website for the full list. |
| 1 | **Brackets, bolts, and fixings** | Everything should be connected tightly or the robot will shake while moving. |
| 1 | **Motor driver with ESP32** | I'm using a custom four-motor driver ESP32-S3 PCB that I designed. The KiCad schematic, PCB layout, and bill of materials are available on the [GitHub repo](https://github.com/jonathanrandall/four_motor_controller). |
| 3 | **3-cell LiPo batteries** | 1 for the Raspberry Pi, 2 connected in series for everything else. |
| 1 | **12V regulator** | Needs enough current to drive the motors. My motors have a 9A stall current, so theoretically ~40A is needed, but I think the one I have can handle ~20A — I wouldn't expect to get close to stall current in normal use. |
| 1 | **Pololu 5V 5.5A Step-Down Voltage Regulator D36V50F5** | The only one I found that could drive the Raspberry Pi without crashing. Other 5V regulators worked under normal load but failed when the Pi CPU was running close to its limits. |
| 2 | **Tungkey 5V USB voltage regulators** | USB output. One for the touchscreen, one for everything else needing 5V. |
| 1 | **Variable step-down voltage regulator at 7.5V** | Powers the pan-tilt head servos. |
| 1 | **ESP32 control board for pan-tilt bus servos** | I'm using the Hiwonder pan-tilt with its ESP32 control board. The board has an extra chip for one-wire communication with the bus servos. |
| 1 | **Raspberry Pi 5** | Onboard robot brains. |
| 1 | **USB speaker and microphone** | Connected through a USB/jack converter. |
| 1 | **Waveshare 7" touchscreen** | Input/output touchscreen. |
| 1 | **3D printed parts** | STL files and FreeCAD macros are in the `3d_prints/` directory of this repo. |
| 2 | **Missile switches** | One for the Pi battery, one for the other batteries. |
| 2 | **USB hubs** | One externally powered hub connected to the Pi (should be good quality). One cheap hub for powering various components. |
| 1 | **USB stereo camera** | Connected to the Pi. |
| 1 | **Time-of-flight (ToF) camera** | Arducam ToF, connected via CSI. |
| 4 | **GoBilda Rhino wheels** | 120mm diameter. |

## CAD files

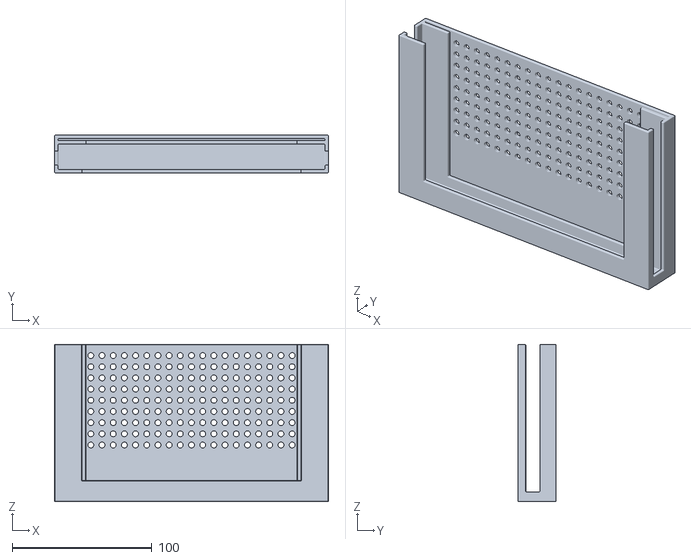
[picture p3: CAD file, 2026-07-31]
3d_prints/Waveshare_Display_holder.stl
196.0 x 27.0 x 112.5

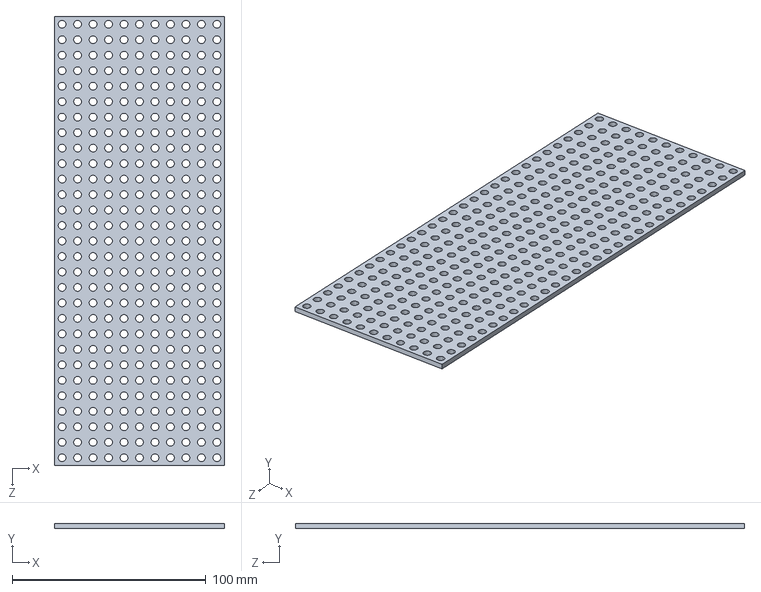
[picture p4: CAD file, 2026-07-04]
from_pi/src/jessica_description/description/meshes/step/grid_88_232.step
88.0 x 2.50 x 232.0 mm

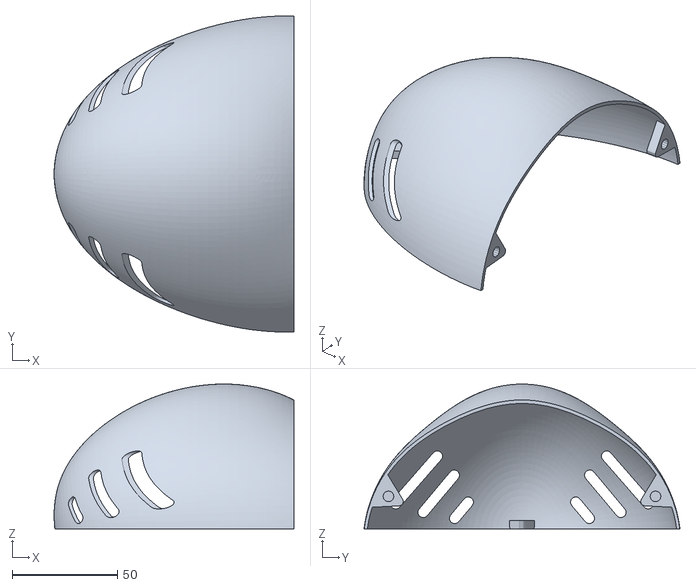
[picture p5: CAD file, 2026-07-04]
from_pi/src/jessica_description/description/meshes/visual/head_top.stl
114.1 x 150.3 x 68.9

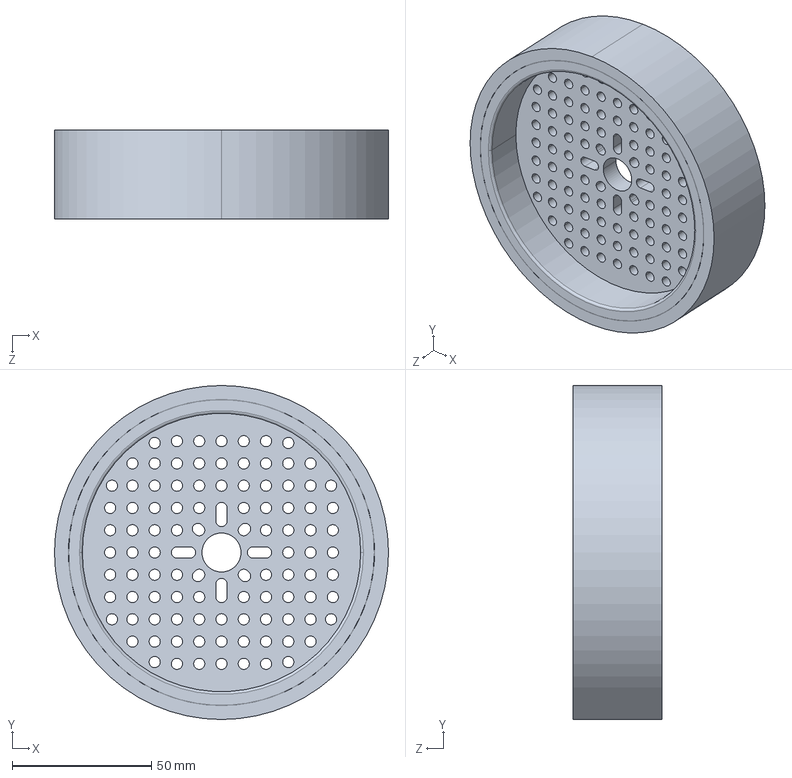
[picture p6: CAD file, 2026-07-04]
robot_pc_ws/src/jessica_description/description/meshes/step/wheel_120.step
120.0 x 120.0 x 32.0 mm

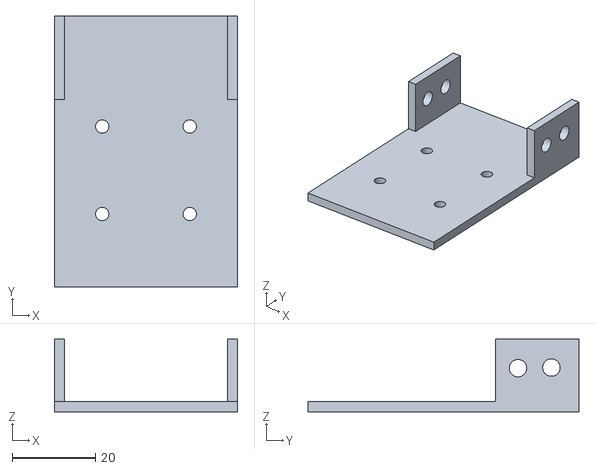
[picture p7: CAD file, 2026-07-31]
3d_prints/pololu_converter_mount.stl
44.0 x 65.0 x 17.5

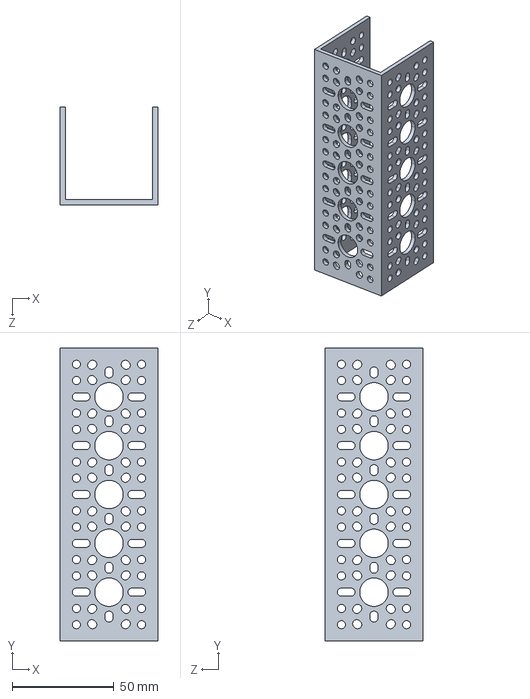
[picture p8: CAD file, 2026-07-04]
from_pi/src/jessica_description/description/meshes/step/cross_bar_144.step
48.0 x 144.0 x 48.0 mm

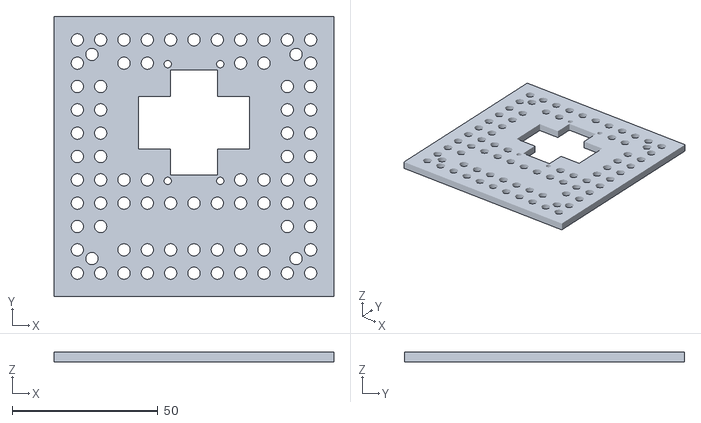
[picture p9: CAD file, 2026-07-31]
3d_prints/HiwonderPanTiltBase.stl
96.0 x 96.0 x 3.50

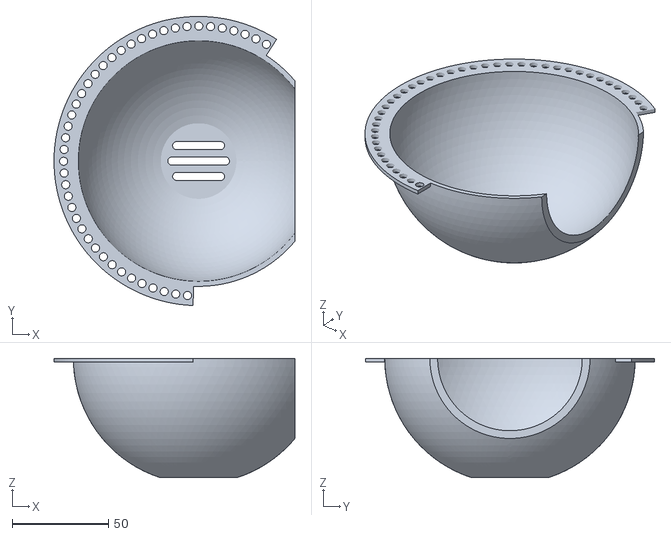
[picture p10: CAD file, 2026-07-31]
3d_prints/wife_boobs_v4.stl
125.0 x 149.9 x 61.8

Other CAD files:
from_pi/src/jessica_description/description/meshes/visual/wheel_120.stl
robot_pc_ws/src/jessica_description/description/meshes/visual/wheel_120.stl
from_pi/src/jessica_description/description/meshes/visual/grid_88_232.stl
robot_pc_ws/src/jessica_description/description/meshes/visual/cross_bar_144.stl
from_pi/src/jessica_description/description/meshes/visual/cross_bar_144.stl
robot_pc_ws/src/jessica_description/description/meshes/visual/grid_88_232.stl
3d_prints/Speaker_Box.stl
3d_prints/Switch_holderv2.stl
3d_prints/battery_holder.stl
3d_prints/buck_converter_mount.stl
3d_prints/camera_holder_robot_face.stl
3d_prints/light_diffuser_Sphere.stl
3d_prints/pi_holder.stl
3d_prints/servo_head_connection-Body.stl
from_pi/src/jessica_description/description/meshes/visual/robot_front.stl
robot_pc_ws/src/jessica_description/description/meshes/visual/robot_front.stl

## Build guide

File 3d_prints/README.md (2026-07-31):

# 3D Prints

STL files and FreeCAD parametric macros for all printed parts on the robot.

| File | Description |
|---|---|
| `battery_holder.stl` | LiPo battery mount |
| `buck_converter_mount.stl` | Buck converter / voltage regulator bracket |
| `camera_holder_robot_face.stl` | Stereo camera mount on the robot face |
| `HiwonderPanTiltBase.stl` | Base bracket for the Hiwonder pan-tilt head |
| `light_diffuser_Sphere.stl` | Hemisphere light diffuser sphere |
| `pi_holder.stl` | Raspberry Pi 5 mount |
| `pololu_converter_mount.stl` | Pololu voltage converter bracket |
| `servo_head_connection-Body.stl` | Pan-tilt servo connection bracket |
| `Speaker_Box.stl` | USB speaker enclosure |
| `Switch_holderv2.stl` | Power switch holder |
| `Waveshare_Display_holder.stl` | Waveshare 7" display mount |
| `wife_boobs_v4.stl` | 3d printed boobs |

FreeCAD parametric source macros are in `macros/`.

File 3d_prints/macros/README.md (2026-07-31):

# FreeCAD Macros

Parametric FreeCAD macros (`.FCMacro`) that generate the STL files in the parent directory. Open in FreeCAD and run to regenerate or modify parts.

| File | Part |
|---|---|
| `batter_box_robot_wife.FCMacro` | Battery box |
| `light_diffuser.FCMacro` | Light diffuser sphere |
| `pan_tilt_base_hiwonder.FCMacro` | Hiwonder pan-tilt base bracket |
| `rpi_holder.FCMacro` | Raspberry Pi mount |
| `speaker_box.FCMacro` | Speaker enclosure |
| `switch_holder.FCMacro` | Power switch holder |
| `waveshare_display.FCMacro` | Waveshare 7" display holder |
| `wife_boobs_claude_v4.FCMacro` | LED diffuser enclosure v4 |

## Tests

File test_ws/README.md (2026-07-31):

# test_ws

Scratch ROS 2 workspace used for testing and developing the robot URDF model in isolation, without needing the full Pi stack running.

Contains a copy of `jessica_description` for iterating on the robot model and previewing it in RViz.

```bash
cd test_ws
colcon build
source install/setup.bash
ros2 launch jessica_description display.launch.py
```

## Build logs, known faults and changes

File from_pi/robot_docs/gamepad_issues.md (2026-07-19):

# Gamepad: mode issues + dual-mode support plan

## ⏭ NEXT: D-mode capture session (paused 2026-07-08, kid's bedtime)

Everything is ready; no launch needed. When Jonny is back:

1. **Jonny**: flip the pad to **D-input mode** (note the combo — still unrecorded!),
   confirm with `~/jessica_ws/gamepad_mode.sh` (should say D-INPUT, 3537:1041), say go.
2. **Claude**: starts a bare `joy_node` in the background and records `/joy` to a file.
   (Nothing else running → no robot reacts to presses. Pad is currently still X-input.)
3. **Jonny performs this sequence, pausing ~1 second between each action:**
   - Left stick: push **LEFT**, release — then push **UP**, release
   - Right stick: push **LEFT**, release — then push **UP**, release
   - Press and release, in order: **A, B, X, Y, LB, RB, LT, RT, View, Menu, Logo**
     (View = small button left of the logo; Menu = small button right of the logo —
     this pad uses Xbox-One-style labels for what 360 pads call Back/Start)
4. **Claude**: stops recording, derives the D-mode axis/button table, **writes the raw
   recorded table below in this file for Jonny to check**, then fills the verified
   numbers (sticks, deadman, and the A/B/Y estop trio) into `config/gamepad_dinput.yaml`
   and rebuilds.
5. **Jonny**: flips back to X-input, `gamepad_mode.sh` confirms, done.

### Recorded D-mode table (captured 2026-07-08, 1965 msgs, 8 axes / 19 buttons)

Raw event order recorded (t = seconds into capture):
sticks redone cleanly at t≈17–31s after a false start; buttons at t≈35–48s in
the order **0, 1, 3, 4, 8(+axis5), 9(+axis4), 6, 7, 10, 11, 12** — i.e. Jonny
pressed the triggers before the bumpers. Buttons 8/9 co-fired analog axes
resting at +1.0 (one a partial half-pull), proving 8/9 are the triggers; the
whole layout is the standard Linux HID BTN_ ordering.

| Control | D-mode index | Notes |
|---|---|---|
| Left stick X | axis 0 | left = + |
| Left stick Y | axis 1 | up = + |
| Right stick X | axis 2 | left = + (old config's guess confirmed) |
| Right stick Y | axis 3 | up = + |
| RT analog | axis 4 | rests +1.0, pulled → −1.0 |
| LT analog | axis 5 | rests +1.0, pulled → −1.0 |
| D-pad | axes 6/7 | assumed, not captured |
| A | button 0 | |
| B | button 1 | |
| X | button 3 | (button 2 is a reserved gap) |
| Y | button 4 | |
| LB | button 6 | old deadman — so it was LB all along, same as X-profile |
| RB | button 7 | (button 5 is a reserved gap) |
| LT digital | button 8 | fires alongside axis 5 |
| RT digital | button 9 | fires alongside axis 4 |
| View | button 10 | |
| Menu | button 11 | |
| Logo | button 12 | |

Applied to `config/gamepad_dinput.yaml` (sticks/deadman confirmed, estop trio
added as A=0, B=1, Y=4) — profile no longer a guess. Raw capture kept this
session at scratchpad/joy_capture.yaml (temporary).

*Written 2026-07-07. Status: **IMPLEMENTED 2026-07-08** — auto-detect built as planned, offline-tested, clean-rebuilt. Still outstanding: (1) the 5-minute D-mode capture session to replace the guessed values in `gamepad_dinput.yaml`, (2) record the pad's mode-switch combo here. Also fixed: `gamepad_mode.sh` no longer kills the shell when sourced with no dongle (uses `return`, not `exit`).*

## Background (what happened today)

The pad is a Zikway 2.4G "XBOX 360 For Windows" clone with **three modes**, distinguishable by USB product ID:

| USB ID | Mode | Kernel driver | Works? |
|---|---|---|---|
| `3537:1040` | **X-input** | `xpad` ("Generic X-Box pad") | ✅ what configs now expect |
| `3537:1041` | D-input | `usbhid` ("HID gamepad") | joystick exists, different axis/button numbering |
| `3537:2106` | Switch/Android? | none | ❌ dead — no js device at all, looks like a broken dongle |

It flipped from D-input to X-input during the battery recharge, which broke the old configs
(head pinned by LT resting at +1.0 on axis 2, wheels dead because the deadman button became an axis).
Configs were remapped to X-input: right stick = head (pan axis 3, tilt axis 4), **hold LB (button 4)**
= drive deadman, RB (5) = turbo, A/B/Y = recentre/estop-clear/estop.

Check the mode any time with: `~/jessica_ws/gamepad_mode.sh` (detects all three states).
Mode is toggled by a combo on the pad — **TODO: record the exact combo that worked** (not yet noted).
X-input axes: 0=LX 1=LY 2=LT 3=RX 4=RY 5=RT — never map 2/5, triggers rest at +1.0.

## The plan: auto-detect mode at launch (option 1, agreed, not yet built)

**Config files: consolidate to one yaml per pad personality.** Currently the mode-dependent
settings are smeared across `joystick.yaml` (drive axes + enable buttons) and
`joy_button_mappings.yaml` (A/B/Y indices), while `pan_tilt_teleop`'s axes are hard-coded
defaults in its Python. Replace with:

- `config/gamepad_xinput.yaml` — sections for all four joystick nodes: `joy_node` (device,
  deadzone), `teleop_node` (drive axes/scales, enable LB=4, turbo RB=5), `pan_tilt_teleop`
  (pan_axis 3, tilt_axis 4), `joy_button_bridge` (A=0 recentre, B=1 estop-clear, Y=3 estop)
- `config/gamepad_dinput.yaml` — the same sections with D-mode numbers (filled in properly
  after the capture session; until then the estop mappings stay empty rather than guessed)

So "one file completely describes one mode" — the old two yamls retire.

**Launch file: the only real code change.** The four joystick `Node(...)` definitions move
inside an `OpaqueFunction` — a launch construct that runs a Python function at launch time,
which lets us inspect the hardware before declaring the nodes. Roughly:

```python
def gamepad_nodes(context):
    mode = LaunchConfiguration("gamepad_mode").perform(context)   # auto | xinput | dinput
    if mode == "auto":
        out = subprocess.run(["udevadm", "info", "-q", "property", "/dev/input/js0"], ...)
        mode = "xinput" if "ID_USB_DRIVER=xpad" in out.stdout else "dinput"
        # no js0 at all (dead 2106 mode / unplugged) -> warn + fall back to xinput
    profile = os.path.join(pkg, "config", f"gamepad_{mode}.yaml")
    return [ joy_node, teleop_drive, pan_tilt_teleop, joy_button_bridge ]   # all with parameters=[profile]
```

Plus a `DeclareLaunchArgument("gamepad_mode", default_value="auto")` so you can force
`gamepad_mode:=xinput` if the detection ever misbehaves. That's ~35–40 lines of launch diff,
mostly moving existing node definitions.

**Node code: zero changes.** `pan_tilt_teleop` already declares `pan_axis`/`tilt_axis` as
parameters — it's just never been handed a yaml. The only touch is that `make_pynode` (the
launch helper) needs to accept a `parameters` argument, or use a plain `Node(...)` for it.

**Behaviour:** launch sniffs the pad once at startup and logs which profile it picked
(`[gamepad] detected X-input → gamepad_xinput.yaml`). Battery-swap flips get absorbed by the
next launch automatically. Mid-session flips still need a relaunch, and the dead `2106` mode
still needs the combo press — no yaml can fix a pad the kernel refuses to make a joystick for.

**Prerequisite:** before `gamepad_dinput.yaml` can hold real numbers, we need a **5-minute
capture session with the pad in D-mode** (Jonny presses each stick/button, Claude reads `/joy`
and writes down the real axis/button table). Until then the D profile ships with the sticks
best-guessed from the old config (pan 2, tilt 3, deadman 6, turbo 7) and the **estop
deliberately unmapped** (a wrongly-mapped estop is worse than a missing one).

**Estimate:** ~30–45 min total. 2 new yamls, 2 old yamls retired, ~40-line launch edit,
no node code changes.

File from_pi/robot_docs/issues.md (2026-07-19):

# Jessica — open issues

## 1. Encoder-health flags: decide what to do when one goes 0 (deferred by design)

The new motor firmware's STATE message carries 4 extra 1/0 flags — one per wheel —
where 0 means "this motor's encoder is not working properly".

What's implemented now (2026-07-14, `esp32_combined_hardware`):
- The 12-field STATE is parsed and the flags are stored in `encoder_ok_[4]`.
- On a 1→0 transition an ERROR is logged naming the wheel joint.
- Nothing else happens: velocities/positions from that wheel are still fed to
  diff_cont as-is.

Still to decide (next session material):
- Should a dead encoder trigger a soft-stop / e-stop, or just degrade odometry?
- diff_cont averages both wheels per side — a wheel with a dead encoder reports
  garbage velocity, polluting odom. Option: drop the bad wheel from the average
  (needs a custom controller or firmware-side handling).
- Expose the flags as custom state interfaces (e.g. for diagnostics /
  a dashboard) instead of just logging?

## 2. ⚠️ New motor firmware is NOT what's flashed (or in temp/) — verified live 2026-07-14

Sending `GET` to `/dev/esp32_motor` returns the OLD 10-field STATE
(`STATE,4×pos,4×vel,pan,tilt`) and the source in `temp/esp32_bridge_servo`
(dated Jul 7) also still prints the old format — no encoder-ok flags anywhere.
The 12-field firmware described for this upgrade exists somewhere else (PC?)
or hasn't been written yet.

The ROS interface handles both:
- 12-field STATE → new protocol, 4-field `CMD,lf,lr,rf,rr`.
- 10-field STATE → logs a one-time warning and falls back to the legacy
  6-field CMD (two trailing zeros) so the robot still drives on old firmware.

**TODO:** flash the real 12-field firmware to the motor ESP32 (and copy its
source into temp/ so it can be inspected here). Assumed new formats — verify
against the real firmware when it lands:
- `STATE,lf_pos,lr_pos,rf_pos,rr_pos,lf_vel,lr_vel,rf_vel,rr_vel,lf_ok,lr_ok,rf_ok,rr_ok`
- `CMD,lf_vel,lr_vel,rf_vel,rr_vel` (cm/s)

## 3. Servo controller (hiwonder head) — notes from bring-up 2026-07-14

- udev rule for `/dev/esp32_servo` written but needs sudo — see below.
- **Position feedback verified working** end-to-end through ros2_control
  (commanded 0.3/-0.2 rad, read back 0.283/-0.184 — quantized to servo units).
  BUT: earlier bench tests returned `position: [null, null]` for a while
  (probably servo power off at the time). If nulls persist, the interface
  logs a warning and reports commanded positions as state (open loop), so the
  head keeps working like the old PCA9685 setup did.
- The board **reboots when the serial port opens** (CH340 DTR) and homes both
  servos to centre; the hardware interface waits `boot_wait_ms` (3 s) for it.
  Every controller_manager start therefore recentres the head — same net
  effect as the launch's home_head step.
- Commands are rate-limited to one `ptr` per 100 ms (`min_send_period_ms`):
  at the full 30 Hz loop rate the board's UART overflows and commands arrive
  mangled (seen live: `{"error": "unknown command: pt9ptr"}`).
- Servo firmware clamps tilt to 220–780 units = ±1.32 rad; URDF tilt limits
  are -1.3..0.87 (tightened from -1.5 to stay inside the clamp).
- **Dead-head incident 2026-07-19, FIXED**: head stopped responding; stack
  looked healthy but /joint_states echoed commands exactly (= open-loop
  fallback). Cause: main.py on the servo board had died to the REPL — its
  loop catches `Exception` but a stray Ctrl-C byte (0x03) on the USB console
  raises `KeyboardInterrupt`, which escapes and kills it. The board then sits
  silent until a reset EDGE; merely reopening the port doesn't make one.
  **Permanent fix in `esp32_servo_hardware` on_configure**: esptool-style
  hard-reset pulse (DTR low + RTS high 100 ms = EN low, then both low = run)
  before the boot wait, so every launch boots fresh firmware and homes the
  head. Gotcha learned: pulsing DTR ALONE leaves (DTR low, RTS high) which
  HOLDS the board in reset on the two-transistor circuit — both lines must
  end deasserted. Verified live: real quantized feedback after launch.
  Bench tool: `temp/test_head_serial.py` (no-ROS serial test with the same
  reset logic + diagnosis; stop the stack first — it checks).
- **Direction signs verified on the real head 2026-07-14**: tilt was mirrored
  (forward/back swapped); fixed with a per-servo `DIRECTIONS` sign map in the
  servo firmware's `config.py` (uploaded to the board via mpremote, local copy
  in temp/micropython_servo_control matches). Pan was correct. User confirmed
  the full launch + head direction test all working. Any future mirrored axis:
  flip it in that map, never in ROS. Direction test script:
  `~/jessica_ws/temp/test_head_directions.sh` (needs the stack running).

## 4. Arducam ToF camera (front, CSI) — WORKING, verified live 2026-07-15

- New package `tof_publisher` publishes `/jessica/tof/image/compressed`
  (PNG, mono8) at 10 Hz; in jessica.launch.py behind `tof:=true` (default).
- Grayscale mapping: `gray = (2000 - depth_mm) * 255 / 2000` → 255 = 0 mm,
  0 = ≥2 m. Invalid pixels (no return/NaN) forced to 0 (far), not 255.
  Camera RANGE control set to 2000 mm. Later: navigation/object avoidance
  on the PC consumes this.
- **The camera is single-client**: a second process calling `start()` spins
  forever at 100% CPU. Close preview_jr.py before launching the stack.
- ⚠️ Killing a client mid-stream can wedge the kernel driver: the process
  survives `kill -9` (stuck in-kernel, R state) and `open()` then hangs for
  everyone until reboot. Seen 2026-07-15 with an orphaned preview_jr.py.
  (Only the second-client-spinning case wedges; a normal streaming process
  being SIGTERMed released the camera cleanly in testing.)
- If the sensor vanishes (SDK says "I2C bus name doesn't match any bus
  present!", dmesg shows `arducam-pivariety 10-000c: probe failed`), it's
  the CSI ribbon — sensor absent from I2C bus 10. Fixed 2026-07-15 by
  reseating the cable. Retry without reboot:
  `echo 10-000c | sudo tee /sys/bus/i2c/drivers/arducam-pivariety/bind`
- Live-verified: 240x180 @ 10.000 Hz, ~28 KB/frame PNG, correct grayscale,
  camera reopens cleanly across restarts.

## 5. udev rule — DONE 2026-07-14

`/etc/udev/rules.d/99-esp32-servo.rules`: CH340 1a86:7523 → `/dev/esp32_servo`.
Applied and verified; full ros2_control bring-up then tested on the REAL ports:
both hardware systems + diff_cont + pan_tilt_controller + joint_broad all
activated, /joint_states carries all 6 joints with live servo feedback, and
the legacy-firmware fallback warning fired as designed (issue 2 still open).
(Motor board keeps its rule: ESP32-S3 303a:1001 → /dev/esp32_motor.)

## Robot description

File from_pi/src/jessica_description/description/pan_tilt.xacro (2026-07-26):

<?xml version="1.0"?>
<!--
  Pan-tilt head assembly: two MG996-form-factor servos, pan on the bottom,
  tilt on top of a ~10mm coupler, real head mesh mounted on a 50mm U-bracket
  on the tilt output.

  This replaces the old placeholder "mast" - the pan servo now sits on a
  short 5mm neck riser on top of `body_top` (see frame.xacro), so the head
  sits roughly 300mm lower than the old tall-mast placeholder did.

  Head mesh: eva_head_frontBottom-part.stl's native origin looks like it's
  already at the mounting/attachment point (X and Z are off-centre toward
  one end, Y is exactly symmetric, consistent with a "front-bottom" mount
  reference) - mounted here with no extra offset as a first guess. Check the
  orientation/offset visually in RViz and tell me what to adjust.
-->
<robot xmlns:xacro="http://www.ros.org/wiki/xacro">

  <xacro:macro name="mg996_servo" params="xyz rpy">
    <visual>
      <origin xyz="${xyz}" rpy="${rpy}"/>
      <geometry><box size="${servo_length} ${servo_width} ${servo_height}"/></geometry>
      <material name="black"/>
    </visual>
    <collision>
      <origin xyz="${xyz}" rpy="${rpy}"/>
      <geometry><box size="${servo_length} ${servo_width} ${servo_height}"/></geometry>
    </collision>
  </xacro:macro>

  <joint name="neck_joint" type="fixed">
    <parent link="body_top"/>
    <child link="neck"/>
    <origin xyz="0.005 0 0" rpy="0 0 0"/>
  </joint>
  <link name="neck">
    <visual>
      <origin xyz="0 0 ${neck_height/2}" rpy="0 0 0"/>
      <geometry><cylinder radius="0.015" length="${neck_height}"/></geometry>
      <material name="gray"/>
    </visual>
    <collision>
      <origin xyz="0 0 ${neck_height/2}" rpy="0 0 0"/>
      <geometry><cylinder radius="0.015" length="${neck_height}"/></geometry>
    </collision>
  </link>

  <joint name="pan_servo_joint" type="fixed">
    <parent link="neck"/>
    <child link="pan_servo"/>
    <origin xyz="0 0 ${neck_height}" rpy="0 0 0"/>
  </joint>
  <link name="pan_servo">
    <!-- shaft (servo_height axis) points straight up -->
    <xacro:mg996_servo xyz="0 0 ${servo_height/2}" rpy="0 0 0"/>
  </link>

  <!-- pan: yaw about Z -->
  <joint name="pan_joint" type="revolute">
    <parent link="pan_servo"/>
    <child link="tilt_mount"/>
    <origin xyz="0 0 ${servo_height}" rpy="0 0 0"/>
    <axis xyz="0 0 1"/>
    <limit lower="-2.356" upper="2.356" effort="5.0" velocity="3.0"/>
  </joint>
  <link name="tilt_mount">
    <!-- coupler between the pan servo's output and the tilt servo -->
    <visual>
      <origin xyz="0 0 ${pan_tilt_spacer_height/2}" rpy="0 0 0"/>
      <geometry><cylinder radius="0.008" length="${pan_tilt_spacer_height}"/></geometry>
      <material name="gray"/>
    </visual>
    <collision>
      <origin xyz="0 0 ${pan_tilt_spacer_height/2}" rpy="0 0 0"/>
      <geometry><cylinder radius="0.008" length="${pan_tilt_spacer_height}"/></geometry>
    </collision>
    <!-- tilt servo mounted directly on top of the coupler, shaft (servo_height axis) horizontal along Y.
         Box origin = box centre, so its bottom edge (half of servo_width,
         the rotated box's vertical extent) needs to sit at the coupler's
         top - otherwise the box swallows most of the cylinder below it. -->
    <xacro:mg996_servo xyz="0 0 ${pan_tilt_spacer_height + servo_width/2}" rpy="${pi/2} 0 0"/>
  </link>

  <!-- tilt: pitch about Y -->
  <joint name="tilt_joint" type="revolute">
    <parent link="tilt_mount"/>
    <child link="head"/>
    <origin xyz="0 0 ${pan_tilt_spacer_height + servo_width/2}" rpy="0 0 0"/>
    <axis xyz="0 1 0"/>
    <limit lower="-1.5" upper="0.87" effort="5.0" velocity="3.0"/>
  </joint>
  <link name="head">
    <!-- U-bracket the head sits on, straddling the tilt servo's rotation
         axis (Y) with an arm on each side, rising to head_bracket_height. -->
    <visual>
      <origin xyz="0 ${head_bracket_arm_spacing/2} ${head_bracket_height/2}" rpy="0 0 0"/>
      <geometry><box size="0.03 ${head_bracket_arm_thickness} ${head_bracket_height}"/></geometry>
      <material name="gray"/>
    </visual>
    <collision>
      <origin xyz="0 ${head_bracket_arm_spacing/2} ${head_bracket_height/2}" rpy="0 0 0"/>
      <geometry><box size="0.03 ${head_bracket_arm_thickness} ${head_bracket_height}"/></geometry>
    </collision>
    <visual>
      <origin xyz="0 ${-head_bracket_arm_spacing/2} ${head_bracket_height/2}" rpy="0 0 0"/>
      <geometry><box size="0.03 ${head_bracket_arm_thickness} ${head_bracket_height}"/></geometry>
      <material name="gray"/>
    </visual>
    <collision>
      <origin xyz="0 ${-head_bracket_arm_spacing/2} ${head_bracket_height/2}" rpy="0 0 0"/>
      <geometry><box size="0.03 ${head_bracket_arm_thickness} ${head_bracket_height}"/></geometry>
    </collision>

    <!-- head mesh sits on top of the bracket. head_bottom.stl's own bottom
         surface is 43.758mm below its mesh origin (bounding-box zmin), so
         the origin needs to sit that much above head_bracket_height for the
         head's actual bottom face - not its origin point - to land on the
         bracket top. -->
    <visual>
      <origin xyz="0.04 0 ${head_bracket_height + 0.043758}" rpy="0 0 0"/>
      <geometry><mesh filename="package://jessica_description/description/meshes/visual/head_bottom.stl" scale="0.001 0.001 0.001"/></geometry>
      <material name="white"/>
    </visual>
    <!-- head_top's bounding box lines up with head_bottom's almost exactly
         (same Y symmetry, same X range) - both STLs share a common native
         origin from the same assembly, so the same offset applies here too. -->
    <visual>
      <origin xyz="0.04 0 ${head_bracket_height + 0.043758}" rpy="0 0 0"/>
      <geometry><mesh filename="package://jessica_description/description/meshes/visual/head_top.stl" scale="0.001 0.001 0.001"/></geometry>
      <material name="white"/>
    </visual>
  </link>

</robot>

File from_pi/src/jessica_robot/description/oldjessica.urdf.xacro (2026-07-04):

<?xml version="1.0"?>
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
<robot xmlns:xacro="http://www.ros.org/wiki/xacro" name="jessica">

  <xacro:arg name="use_ros2_control" default="true"/>
  <xacro:arg name="sim_mode" default="false"/>

  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
  <xacro:property name="wheel_radius" value="0.072"/>
  <xacro:property name="wheel_width" value="0.04"/>
  <xacro:property name="wheel_sep_y" value="0.13"/>   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
  <xacro:property name="wheel_sep_x" value="0.10"/>   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
  <xacro:property name="chassis_length" value="0.30"/>
  <xacro:property name="chassis_width" value="0.22"/>
  <xacro:property name="chassis_height" value="0.10"/>

  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
  <link name="base_link"/>

  <joint name="base_footprint_joint" type="fixed">
    <parent link="base_link"/>
    <child link="base_footprint"/>
    <origin xyz="0 0 0" rpy="0 0 0"/>
  </joint>
  <link name="base_footprint"/>

  <joint name="chassis_joint" type="fixed">
    <parent link="base_link"/>
    <child link="chassis"/>
    <origin xyz="0 0 ${wheel_radius}" rpy="0 0 0"/>
  </joint>
  <link name="chassis">
    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
  </link>

  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
  <xacro:macro name="wheel" params="name x y reflect">
    <link name="${name}">
      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
    </link>
    <joint name="${name}_joint" type="continuous">
      <parent link="base_link"/>
      <child link="${name}"/>
      <origin xyz="${x} ${y} ${wheel_radius}" rpy="0 0 0"/>
      <axis xyz="0 1 0"/>
    </joint>
  </xacro:macro>

  <xacro:wheel name="left_front_wheel" x="${ wheel_sep_x}" y="${ wheel_sep_y}" reflect="1"/>
  <xacro:wheel name="left_rear_wheel" x="${-wheel_sep_x}" y="${ wheel_sep_y}" reflect="1"/>
  <xacro:wheel name="right_front_wheel" x="${ wheel_sep_x}" y="${-wheel_sep_y}" reflect="-1"/>
  <xacro:wheel name="right_rear_wheel" x="${-wheel_sep_x}" y="${-wheel_sep_y}" reflect="-1"/>

  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
  <xacro:property name="mast_height" value="0.35"/>

  <joint name="mast_joint" type="fixed">
    <parent link="chassis"/>
    <child link="mast"/>
    <origin xyz="0 0 ${chassis_height}" rpy="0 0 0"/>
  </joint>
  <link name="mast">
    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
  </link>

  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
  <joint name="pan_joint" type="revolute">
    <parent link="mast"/>
    <child link="pan_link"/>
    <origin xyz="0 0 ${mast_height}" rpy="0 0 0"/>
    <axis xyz="0 0 1"/>
    <limit lower="-1.57" upper="1.57" effort="5.0" velocity="3.0"/>
  </joint>
  <link name="pan_link">
    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
  </link>

  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
  <joint name="tilt_joint" type="revolute">
    <parent link="pan_link"/>
    <child link="head"/>
    <origin xyz="0 0 0.05" rpy="0 0 0"/>
    <axis xyz="0 1 0"/>
    <limit lower="-1.5" upper="0.87" effort="5.0" velocity="3.0"/>
  </joint>
  <link name="head">
    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
  </link>

  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
  <xacro:if value="$(arg use_ros2_control)">
    <ros2_control name="JessicaESP32" type="system">
      <hardware>
        <plugin>esp32_combined_hardware/ESP32CombinedHardware</plugin>
        <param name="device">/dev/esp32_motor</param>
        <param name="baud_rate">115200</param>
        <param name="timeout_ms">25</param>   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

        <param name="wheel_radius">7.2</param>        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
        <param name="enc_counts_per_rev">1425</param>
      </hardware>

      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
      <joint name="left_front_wheel_joint">
        <command_interface name="velocity"><param name="min">-10</param><param name="max">10</param></command_interface>
        <state_interface name="position"/>
        <state_interface name="velocity"/>
      </joint>
      <joint name="left_rear_wheel_joint">
        <command_interface name="velocity"><param name="min">-10</param><param name="max">10</param></command_interface>
        <state_interface name="position"/>
        <state_interface name="velocity"/>
      </joint>
      <joint name="right_front_wheel_joint">
        <command_interface name="velocity"><param name="min">-10</param><param name="max">10</param></command_interface>
        <state_interface name="position"/>
        <state_interface name="velocity"/>
      </joint>
      <joint name="right_rear_wheel_joint">
        <command_interface name="velocity"><param name="min">-10</param><param name="max">10</param></command_interface>
        <state_interface name="position"/>
        <state_interface name="velocity"/>
      </joint>

      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
      <joint name="pan_joint">
        <command_interface name="position"><param name="min">-1.57</param><param name="max">1.57</param></command_interface>
        <state_interface name="position"/>
      </joint>
      <joint name="tilt_joint">
        <command_interface name="position"><param name="min">-1.5</param><param name="max">0.87</param></command_interface>
        <state_interface name="position"/>
      </joint>
    </ros2_control>
  </xacro:if>

</robot>

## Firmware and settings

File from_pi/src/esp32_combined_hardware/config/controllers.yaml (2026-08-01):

controller_manager:
  ros__parameters:
    update_rate: 50  # Hz

    diff_drive_controller:
      type: diff_drive_controller/DiffDriveController

    pan_tilt_controller:
      type: joint_trajectory_controller/JointTrajectoryController

    joint_state_broadcaster:
      type: joint_state_broadcaster/JointStateBroadcaster

diff_drive_controller:
  ros__parameters:
    left_wheel_names: ['left_front_wheel_joint', 'left_rear_wheel_joint']
    right_wheel_names: ['right_front_wheel_joint', 'right_rear_wheel_joint']

    wheel_separation: 0.282  # meters (2 x wheel_sep_y from jessica_description dimensions.xacro)
    wheel_radius: 0.06      # meters (gobilda 144mm wheel)

    publish_rate: 50.0
    odom_frame_id: odom
    base_frame_id: base_link
    pose_covariance_diagonal: [0.001, 0.001, 0.001, 0.001, 0.001, 0.01]
    twist_covariance_diagonal: [0.001, 0.001, 0.001, 0.001, 0.001, 0.01]

    open_loop: false
    enable_odom_tf: true

    cmd_vel_timeout: 0.5
    use_stamped_vel: false

pan_tilt_controller:
  ros__parameters:
    joints:
      - pan_joint
      - tilt_joint

    command_interfaces:
      - position

    state_interfaces:
      - position

    allow_partial_joints_goal: false
    allow_integration_in_goal_trajectories: true

    constraints:
      stopped_velocity_tolerance: 0.01
      goal_time: 0.0

joint_state_broadcaster:
  ros__parameters:
    extra_joints: []

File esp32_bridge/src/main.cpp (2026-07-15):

#include <Arduino.h>
#include <ESPmDNS.h>
#include "Mcp23017Bus.h"
#include "Motor.h"
#include "RobotController.h"
#include "WebDashboard.h"
#include "DebugLog.h"

// ============================================================================
// CONFIGURATION - Modify these values as needed
// ============================================================================

// WiFi credentials
const char* WIFI_SSID = "WiFi-";
const char* WIFI_PASSWORD = "";

// mDNS hostname (access via http://robot.local)
const char* MDNS_HOSTNAME = "robot";

// Robot physical parameters
const RobotParams ROBOT_PARAMS = {
    0.144f,     // wheelDiameterM: Wheel diameter in meters (90mm)
    1425.0f,     // encoderCPR: Encoder counts per revolution
    0.20f,      // wheelBaseM: Distance between left/right wheels (200mm)
    0.8f        // maxSpeedMPS: Maximum speed in m/s (measured ~80 cm/s;
                //   must match MAX_SPEED_MPS in the dashboard JS)
};

// ============================================================================
// HARDWARE PINS
// ============================================================================

// Shared pins
constexpr int PIN_SDA = 16;
constexpr int PIN_SCL = 15;

// MCP23017 address
constexpr uint8_t MCP_ADDR = 0x20;

// MCP23017 LED pins
constexpr uint8_t MCP_RED_LED   = 1;  // GPA1
constexpr uint8_t MCP_GREEN_LED = 2;  // GPA2

// Auxiliary output
constexpr int PIN_AUX_OUT = 42;

// Motor pin configurations
// MotorPins: mcpINA, mcpINB, mcpSEL0, mcpSEL1, pwmGPIO, csAdcGPIO, encA, encB
// SEL0=GPA5(5), SEL1=GPA6(6) are shared across all four drivers
const MotorPins M1_PINS = {3,  0,  5, 6, 8,  4, 17, 7};
const MotorPins M2_PINS = {15, 12, 5, 6, 48, 1, 38, 39};  // encA/B swapped (left side)
const MotorPins M3_PINS = {11, 8,  5, 6, 13, 2, 14, 47};  // encA/B swapped (left side)
const MotorPins M4_PINS = {7,  4,  5, 6, 9,  5, 11, 12};

// Motor configuration
const MotorConfig MOTOR_CONFIG = {20000, 10, false, 0.14f, 0.0f, 3.0f};

// ============================================================================
// FREERTOS CONFIGURATION
// ============================================================================

constexpr uint32_t MOTOR_TASK_STACK_SIZE = 4096;
constexpr uint32_t MOTOR_TASK_PRIORITY = 5;
constexpr uint32_t MOTOR_UPDATE_INTERVAL_MS = 10;

constexpr uint32_t TELEMETRY_TASK_STACK_SIZE = 4096;
constexpr uint32_t TELEMETRY_TASK_PRIORITY = 2;
constexpr uint32_t TELEMETRY_UPDATE_INTERVAL_MS = 50;

constexpr uint32_t SERIAL_CMD_TASK_STACK_SIZE = 4096;
constexpr uint32_t SERIAL_CMD_TASK_PRIORITY   = 3;
constexpr uint32_t SERIAL_WATCHDOG_MS         = 1000;

// ============================================================================
// GLOBAL OBJECTS
// ============================================================================

Mcp23017Bus mcp;
Motor* motors[4];
RobotController*   robot    = nullptr;
WebDashboard*      dashboard = nullptr;

// Task handles
TaskHandle_t motorTaskHandle     = nullptr;
TaskHandle_t telemetryTaskHandle = nullptr;
TaskHandle_t serialCmdTaskHandle = nullptr;

// Serial command watchdog — set to millis() on each motor command, 0 = no command received yet
volatile uint32_t lastMotorCommandMs = 0;

// Auxiliary pin state — shared with WebDashboard for telemetry
volatile bool g_auxPinHigh = false;

// Emergency stop latch — set by AUX,estop or /api/estop, cleared by
// AUX,estopclear or /api/estop?state=0. While active, incoming CMD
// velocity commands are ignored.
volatile bool g_eStopActive = false;

// Set by the serial watchdog on comms timeout, cleared by the next CMD.
//
// Both flags are only *requests*: motorControlTask is the single writer
// of motor state and performs the disable+brake (and the re-enable when
// the condition clears). Braking directly from another task/core could
// be overwritten by an in-flight PID cycle's setDuty() calls.
volatile bool g_watchdogBrake = false;

// Set by AUX,estopclear / the dashboard CLEAR button; motorControlTask
// resets the wheel-fault latches (limp / stall — see RobotController wheel
// fault supervision) when it sees this.
volatile bool g_faultClearRequest = false;


// Telemetry data (shared between tasks)
struct TelemetryData {
    int64_t encoderCounts[4];
    float motorCurrents[4];
    float actualSpeed;
    SemaphoreHandle_t mutex;
} telemetry;

// ============================================================================
// SERIAL COMMAND PROTOCOL (ROS2 diff drive interface)
//
// Messages FROM PC → ESP32 (terminated by \n):
//   "GET\n"
//       — request current state; ESP32 responds immediately with STATE message
//   "CMD,lf_vel,lr_vel,rf_vel,rr_vel\n"
//       — set per-wheel speeds (cm/s, float); extra trailing fields are ignored
//   "AUX,command_name,arg\n"
//       — auxiliary commands, including:
//           AUX,estop       — emergency stop: brake + disable motors, ignore CMD until cleared
//           AUX,estopclear  — clear emergency stop and wheel-fault latches,
//                             resume normal CMD control
//
// Messages FROM ESP32 → PC (in response to GET):
//   "STATE,lf_pos,lr_pos,rf_pos,rr_pos,lf_vel,lr_vel,rf_vel,rr_vel,lf_ok,lr_ok,rf_ok,rr_ok\n"
//       — encoder counts (int), wheel velocities (cm/s, float), and wheel
//         health flags (1 = OK, 0 = faulted: encoder untrusted/limping or
//         stall-latched — see RobotController wheel fault supervision).
//         A faulted wheel's velocity is untrustworthy — exclude it from
//         odometry.
//
// Wheel order: lf=FL(M3), lr=RL(M2), rf=FR(M4), rr=RR(M1)
// ============================================================================

void sendStateMessage() {
    // Encoder positions (cumulative counts, integer)
    int64_t lf_pos = robot->getEncoderCount(FRONT_LEFT);
    int64_t lr_pos = robot->getEncoderCount(REAR_LEFT);
    int64_t rf_pos = robot->getEncoderCount(FRONT_RIGHT);
    int64_t rr_pos = robot->getEncoderCount(REAR_RIGHT);

    // Wheel velocities in cm/s
    float lf_vel = robot->getFrontLeftWheelSpeed()  * 100.0f;
    float lr_vel = robot->getRearLeftWheelSpeed()   * 100.0f;
    float rf_vel = robot->getFrontRightWheelSpeed() * 100.0f;
    float rr_vel = robot->getRearRightWheelSpeed()  * 100.0f;

    Serial.printf("STATE,%lld,%lld,%lld,%lld,%.2f,%.2f,%.2f,%.2f,%d,%d,%d,%d\n",
                  lf_pos, lr_pos, rf_pos, rr_pos,
                  lf_vel, lr_vel, rf_vel, rr_vel,
                  robot->wheelOk(FRONT_LEFT)  ? 1 : 0,
                  robot->wheelOk(REAR_LEFT)   ? 1 : 0,
                  robot->wheelOk(FRONT_RIGHT) ? 1 : 0,
                  robot->wheelOk(REAR_RIGHT)  ? 1 : 0);
}

void processSerialCommand(const String& cmd) {
    if (cmd == "GET") {
        sendStateMessage();
    }
    else if (cmd.startsWith("CMD,")) {
        float lf_vel, lr_vel, rf_vel, rr_vel;
        if (sscanf(cmd.c_str(), "CMD,%f,%f,%f,%f",
                   &lf_vel, &lr_vel, &rf_vel, &rr_vel) == 4) {
            // Serial link is alive — feed the watchdog even while e-stopped
            lastMotorCommandMs = millis();
            g_watchdogBrake = false;

            // Convert cm/s to m/s, average per side for left/right differential drive
            if (!g_eStopActive) {
                float leftMPS  = (lf_vel + lr_vel) / 2.0f / 100.0f;
                float rightMPS = (rf_vel + rr_vel) / 2.0f / 100.0f;
                if (!robot->isEnabled()) robot->enable(true);
                robot->setWheelSpeeds(leftMPS, rightMPS);
            }
        }
    }
    else if (cmd.startsWith("AUX,")) {
        // Parse AUX,command_name,arg
        String rest = cmd.substring(4);
        int comma = rest.indexOf(',');
        String command_name, arg;
        if (comma >= 0) {
            command_name = rest.substring(0, comma);
            arg = rest.substring(comma + 1);
        } else {
            command_name = rest;
            arg = "";
        }
        if (command_name == "toggle") {
            static bool auxPinState = false;
            auxPinState = !auxPinState;
            g_auxPinHigh = auxPinState;
            digitalWrite(PIN_AUX_OUT, auxPinState ? HIGH : LOW);
        } else if (command_name == "fire") {
            if (!g_auxPinHigh) {
                g_auxPinHigh = true;
                digitalWrite(PIN_AUX_OUT, HIGH);
                TimerHandle_t t = xTimerCreate("auxOff", pdMS_TO_TICKS(600), pdFALSE, nullptr,
                    [](TimerHandle_t xTimer) {
                        digitalWrite(PIN_AUX_OUT, LOW);
                        g_auxPinHigh = false;
                        xTimerDelete(xTimer, 0);
                    });
                if (t) xTimerStart(t, 0);
            }
        } else if (command_name == "estop") {
            g_eStopActive = true;   // motorControlTask performs the disable+brake
        } else if (command_name == "estopclear") {
            g_eStopActive = false;  // motorControlTask re-enables when it sees this
            g_faultClearRequest = true;
        }
    }
}

void serialCommandTask(void* parameter) {
    String line = "";
    line.reserve(64);

    while (true) {
        // Watchdog: request a brake if no CMD within timeout. The brake
        // itself is performed by motorControlTask (single writer of motor
        // state); the next CMD clears the flag and resumes normal control.
        uint32_t lastCmd = lastMotorCommandMs;
        if (lastCmd > 0 && (millis() - lastCmd) > SERIAL_WATCHDOG_MS) {
            lastMotorCommandMs = 0;  // reset to prevent repeated triggers
            g_watchdogBrake = true;
        }

        while (Serial.available()) {
            char c = (char)Serial.read();
            if (c == '\r' || c == '\n') {
                if (line.length() > 0) {
                    processSerialCommand(line);
                    line = "";
                }
            } else {
                line += c;
            }
        }

        vTaskDelay(pdMS_TO_TICKS(1));
    }
}

// ============================================================================
// FREERTOS TASKS
// ============================================================================

void motorControlTask(void* parameter) {
    TickType_t lastWakeTime = xTaskGetTickCount();
    const TickType_t interval = pdMS_TO_TICKS(MOTOR_UPDATE_INTERVAL_MS);

    Serial.println("[Motor Task] Started");

    bool wasBraked = false;

    while (true) {
        if (g_faultClearRequest) {
            g_faultClearRequest = false;
            robot->clearWheelFaults();
        }

        // E-stop / watchdog / stall-latch braking happens here, not in the
        // tasks that request it, so the brake can never be overwritten by an
        // in-flight PID cycle. Re-asserted every cycle while active.
        // update() below is a no-op while disabled, and encoder updates
        // continue so reported velocities stay live.
        bool braked = g_eStopActive || g_watchdogBrake || robot->faultLatched();
        if (braked) {
            if (robot->isEnabled()) robot->enable(false);
            robot->brake();
        } else if (wasBraked) {
            robot->enable(true);  // resume after estopclear / comms restored
        }
        wasBraked = braked;

        // Check individual motor faults
        bool fault = false;
        for (int i = 0; i < 4; i++) {
            if (motors[i]->hasFault()) {
                // Runtime print — gated so it can't interleave with STATE
                // lines on the protocol UART (see DebugLog.h)
                DBG_PRINTF("[Motor Task] Motor %d FAULT (code %d)\n", i + 1, motors[i]->faultCode());
                fault = true;
            }
        }

        if (fault) {
            robot->brake();
            vTaskDelay(pdMS_TO_TICKS(1000));
            continue;
        }

        // Update encoder velocities
        for (int i = 0; i < 4; i++) {
            motors[i]->updateEncoder();
        }

        // Update robot controller (applies motor commands)
        robot->update();

        // Wait for next cycle
        vTaskDelayUntil(&lastWakeTime, interval);
    }
}

void telemetryTask(void* parameter) {
    const TickType_t interval = pdMS_TO_TICKS(TELEMETRY_UPDATE_INTERVAL_MS);

    Serial.println("[Telemetry Task] Started");

    while (true) {
        // Update telemetry data with mutex protection
        if (xSemaphoreTake(telemetry.mutex, pdMS_TO_TICKS(10)) == pdTRUE) {
            for (int i = 0; i < 4; i++) {
                telemetry.encoderCounts[i] = motors[i]->getEncoderCount();
                telemetry.motorCurrents[i] = motors[i]->readCurrentAmps();
            }
            telemetry.actualSpeed = robot->getActualLinearSpeed();
            xSemaphoreGive(telemetry.mutex);
        }

        vTaskDelay(interval);
    }
}

// ============================================================================
// SETUP AND MAIN
// ============================================================================

void setup() {
    Serial.begin(115200);
    pinMode(PIN_AUX_OUT, OUTPUT);
    digitalWrite(PIN_AUX_OUT, LOW);
    delay(1000);
    Serial.println("\n========================================");
    Serial.println("  ESP32-S3 Quad Motor Robot Controller");
    Serial.println("========================================\n");

    // Initialize telemetry mutex
    telemetry.mutex = xSemaphoreCreateMutex();

    // Initialize MCP23017
    Serial.print("Initializing MCP23017... ");
    if (!mcp.begin(PIN_SDA, PIN_SCL, MCP_ADDR)) {
        Serial.println("FAILED!");
        while (1) { delay(1000); }
    }
    Serial.println("OK");

    // Configure status LEDs (red=off, green=on to indicate ready)
    mcp.pinMode(MCP_RED_LED,   OUTPUT);
    mcp.pinMode(MCP_GREEN_LED, OUTPUT);
    mcp.writePin(MCP_RED_LED,   LOW);
    mcp.writePin(MCP_GREEN_LED, HIGH);

    // mcp.pinMode(0,   OUTPUT);
    // mcp.pinMode(3, OUTPUT);
    // mcp.writePin(0,   LOW);
    // mcp.writePin(3, HIGH);

    // Serial.println("MCP23017 initialized and LEDs configured");
    // delay(50000);
    // Serial.println("Continuing with motor initialization...");

    // Create motor objects
    motors[0] = new Motor(mcp, M1_PINS, MOTOR_CONFIG);
    motors[1] = new Motor(mcp, M2_PINS, MOTOR_CONFIG);
    motors[2] = new Motor(mcp, M3_PINS, MOTOR_CONFIG);
    motors[3] = new Motor(mcp, M4_PINS, MOTOR_CONFIG);

    // Initialize each motor
    for (int i = 0; i < 4; i++) {
        Serial.printf("Initializing Motor %d... ", i + 1);
        if (!motors[i]->begin(static_cast<pcnt_unit_t>(i))) {
            Serial.println("FAILED!");
            while (1) { delay(1000); }
        }
        Serial.println("OK");
    }

    // Create robot controller
    robot = new RobotController(motors, ROBOT_PARAMS, &mcp, MCP_RED_LED, MCP_GREEN_LED);
    robot->begin();
    Serial.println("Robot controller initialized");

    // Print robot parameters
    Serial.println("\nRobot Parameters:");
    Serial.printf("  Wheel diameter: %.3f m\n", ROBOT_PARAMS.wheelDiameterM);
    Serial.printf("  Encoder CPR: %.0f counts/rev\n", ROBOT_PARAMS.encoderCPR);
    Serial.printf("  Wheel base: %.3f m\n", ROBOT_PARAMS.wheelBaseM);
    Serial.printf("  Max speed: %.2f m/s\n", ROBOT_PARAMS.maxSpeedMPS);

    // Connect to WiFi and start web server
    Serial.println("\nConnecting to WiFi...");
    dashboard = new WebDashboard(*robot);
    if (!dashboard->begin(WIFI_SSID, WIFI_PASSWORD)) {
        Serial.println("WiFi failed - continuing without web dashboard");
    } else {
        // Start mDNS responder
        if (MDNS.begin(MDNS_HOSTNAME)) {
            MDNS.addService("http", "tcp", 80);
            Serial.printf("mDNS started: http://%s.local\n", MDNS_HOSTNAME);
        } else {
            Serial.println("mDNS failed to start");
        }

        Serial.println("\n========================================");
        Serial.print("  Dashboard: http://");
        Serial.println(dashboard->getIP());
        Serial.println("========================================\n");
    }

    // ---- TEST: Drive forward for 5 seconds ----
    // Serial.println("\n[TEST] Driving forward at 0.3 m/s for 5 seconds...");
    // bool prevPIDState = robot->isPIDEnabled();
    // bool tmp = robot->isEnabled();
    // robot->enable(true);
    // robot->forward(0.3f);
    
    // robot->enablePID(false);
    // uint32_t testStart = millis();
    // while (millis() - testStart < 5000) {
    //     for (int i = 0; i < 4; i++) motors[i]->updateEncoder();
    //     robot->update();
    //     delay(10);
    // }
    // robot->brake();
    // robot->enablePID(prevPIDState);
    // robot->enable(tmp);
    // Serial.println("[TEST] Done.\n");
    // ---- END TEST ----

    // Create FreeRTOS tasks
    Serial.println("Starting FreeRTOS tasks...");

    xTaskCreatePinnedToCore(
        motorControlTask,
        "MotorControl",
        MOTOR_TASK_STACK_SIZE,
        nullptr,
        MOTOR_TASK_PRIORITY,
        &motorTaskHandle,
        1  // Run on core 1
    );

    xTaskCreatePinnedToCore(
        telemetryTask,
        "Telemetry",
        TELEMETRY_TASK_STACK_SIZE,
        nullptr,
        TELEMETRY_TASK_PRIORITY,
        &telemetryTaskHandle,
        0  // Run on core 0
    );

    xTaskCreatePinnedToCore(
        serialCommandTask,
        "SerialCmd",
        SERIAL_CMD_TASK_STACK_SIZE,
        nullptr,
        SERIAL_CMD_TASK_PRIORITY,
        &serialCmdTaskHandle,
        0  // Run on core 0
    );

    Serial.println("System ready!\n");
}

void loop() {
    // Main loop is mostly idle - work is done in FreeRTOS tasks
    // Just print status periodically

    static uint32_t lastStatusTime = 0;
    uint32_t now = millis();

    // Status print disabled — Serial is used for ROS2 serial protocol
    (void)lastStatusTime;
    (void)now;

    delay(100);
}

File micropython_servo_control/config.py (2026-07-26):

# Configuration for the serial pan/tilt servo controller.
from math import pi

# --- Servo bus UART pins (xArm ESP32 board) ---
SERVO_TX = 26
SERVO_RX = 35
SERVO_TX_EN = 25
SERVO_RX_EN = 12

# --- Command UART (link to the Pi) ---
CMD_UART_ID = 1
CMD_UART_TX = 17
CMD_UART_RX = 16
CMD_UART_BAUD = 115200

# --- OLED I2C pins ---
OLED_SCL = 27
OLED_SDA = 14

# --- Servo IDs ---
PAN_ID = 6   # servo 6 = pan
TILT_ID = 5  # servo 5 = tilt

# Joint names reported in the JointState-style reply, in report order.
JOINT_NAMES = {
    PAN_ID: 'pan_joint',
    TILT_ID: 'tilt_joint',
}
JOINT_ORDER = (PAN_ID, TILT_ID)

# --- Motion ---
DEFAULT_MS = 500       # default move duration in ms
CENTER_UNITS = 500     # boot / home position

# Per-servo position limits in servo units (full servo range is 0-1000).
LIMITS = {
    PAN_ID: (0, 1000),
    TILT_ID: (220, 780),
}

# --- Unit <-> radian mapping ---
# 500 units = 0 rad, 1000 units = +135 deg, 0 units = -135 deg.
HALF_RANGE_UNITS = 500
HALF_RANGE_RAD = 135 * pi / 180

# Per-servo direction sign: ROS conventions are +pan = left, +tilt = down.
# Tilt was mirrored here (verified on the head 2026-07-14) because increasing
# units used to tip the head BACK (up) on that servo. After the 2026-07-22
# servo swap the tilt axis reads the other way round — following now runs
# away to the tilt-back limit instead of centering, the signature of an
# inverted direction — so this is flipped to +1. Flip a sign here — never
# in ROS — if a direction test shows a mirrored axis.
DIRECTIONS = {
    PAN_ID: 1,
    TILT_ID: 1,
}


def units_to_rad(servo_id, p):
    d = DIRECTIONS.get(servo_id, 1)
    return d * (p - CENTER_UNITS) * HALF_RANGE_RAD / HALF_RANGE_UNITS


def rad_to_units(servo_id, r):
    d = DIRECTIONS.get(servo_id, 1)
    return int(round(CENTER_UNITS + d * r * HALF_RANGE_UNITS / HALF_RANGE_RAD))


def clamp(servo_id, p):
    lo, hi = LIMITS.get(servo_id, (0, 1000))
    return max(lo, min(hi, p))

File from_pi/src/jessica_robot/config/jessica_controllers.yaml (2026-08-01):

controller_manager:
  ros__parameters:
    update_rate: 30  # Hz (33ms budget; serial GET/STATE round-trip must fit inside this)

    diff_cont:
      type: diff_drive_controller/DiffDriveController

    pan_tilt_controller:
      type: joint_trajectory_controller/JointTrajectoryController

    joint_broad:
      type: joint_state_broadcaster/JointStateBroadcaster

diff_cont:
  ros__parameters:
    left_wheel_names:  ['left_front_wheel_joint', 'left_rear_wheel_joint']
    right_wheel_names: ['right_front_wheel_joint', 'right_rear_wheel_joint']

    # From the real gobilda build (jessica_description dimensions.xacro):
    # track = 2 x wheel_sep_y = 2 x 0.151. Skid-steer scrub means the EFFECTIVE
    # separation is usually a bit larger — calibrate with the twirl test
    # (command 1 rotation, scale this by actual/commanded rotation).
    wheel_separation: 0.282  # metres (centre-to-centre, left↔right)
    wheel_radius:     0.06  # metres (gobilda 144mm wheel)

    publish_rate: 30.0
    odom_frame_id: odom
    base_frame_id: base_link
    pose_covariance_diagonal:  [0.001, 0.001, 0.001, 0.001, 0.001, 0.01]
    twist_covariance_diagonal: [0.001, 0.001, 0.001, 0.001, 0.001, 0.01]

    open_loop: false
    enable_odom_tf: true

    cmd_vel_timeout: 0.5
    use_stamped_vel: true   # receives geometry_msgs/TwistStamped on ~/cmd_vel

pan_tilt_controller:
  ros__parameters:
    joints:
      - pan_joint
      - tilt_joint

    command_interfaces:
      - position

    state_interfaces:
      - position

    # Open-loop servos: state mirrors last command, so keep tolerances loose.
    allow_partial_joints_goal: false
    allow_integration_in_goal_trajectories: true

    constraints:
      stopped_velocity_tolerance: 0.0
      goal_time: 0.0

# joint_broad (joint_state_broadcaster) needs no params — it publishes all
# hardware joints by default. NOTE: do NOT add `extra_joints: []` here — an
# empty YAML list has no inferable type and makes the controller fail to load
# ("parameter_value_from failed for parameter 'extra_joints'"), which silently
# kills /joint_states.

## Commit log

2026-06-28 first update for this repo, more to come
    [Hemisphere-Editable_13mm_Inner_Radius_Hemisphere001.stl, Speaker_Box.stl, Switch_holderv2.stl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]
2026-07-04 updated pc stuff
    [jessica.urdf.xacro, jessica_controllers.yaml]
2026-07-04 test urdf
    [1116-0088-0232.STEP, 1120-0005-0144.STEP, 3601-0014-0120 part.STEP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]
2026-07-04 new urdf and finger follower
    [1116-0088-0232.STEP, 1120-0005-0144.STEP, 3601-0014-0120 part.STEP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]
2026-07-05 update finger follower
    [jessica_controllers.yaml]
2026-07-06 added following and stop signal
    [cross_bar_144.step, cross_bar_144.stl, dimensions.xacro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]
2026-07-07 a few fixes
    [dimensions.xacro, jessica.urdf.xacro, jessica_controllers.yaml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]
2026-07-15 servo head replace
    [ros2_control.xacro]
2026-07-26 lots of changes
    [body_432.step, controllers.yaml, cross_bar_144.step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]
2026-07-31 3d print files
    [Hemisphere-Editable_13mm_Inner_Radius_Hemisphere001.stl, HiwonderPanTiltBase.stl, Waveshare_Display_holder.stl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]
2026-07-31 esp32 stuff
2026-08-01 pi stuff updated
    [controllers.yaml, dimensions.xacro, jessica_controllers.yaml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]
